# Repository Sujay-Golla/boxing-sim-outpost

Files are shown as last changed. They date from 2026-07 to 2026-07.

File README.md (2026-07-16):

# Boxing Simulator
By: Sujay Golla, Arush Sastry, Sreekar

## Inspiration
The inspiration for this project partially comes from VR experience, which uses body sensors to let users experience and interact with a different reality. Combined with our shared interests for combat sports, we chose to use robotic arms to simulate a boxing game and create a fun and interactive demo for Open Sauce.

## Challenges
The time constraint was the biggest challenge in designing, prototyping and refining our project. Since it was a hackathon, a lot of the wiring and 3D models were initial iterations and had to be adapted to create a working demo. Initially we were planning to make it a two-player interactive game but we had to scope it down to accomodate for the materials and timing constraints to a one-player score-based boxing game.

## Technical Features
The project involves a pair of 3-DOF robotic arms controlled by MPU-6050 IMU sensors in the form of an armband that users can wear to interact the board. Depending on the complexity and execution of a boxing move, players can score points and finish objectives. In a two-player extension, a boxing spar would take place, where the player with the most points would win. 

## CAD Model


## Wiring Diagram


## BOM

| Item Name | Qty | Price (USD) | Links |
|---|---:|---:|---|
| Orpheus Pi Pico | 1 | ~$5 | [Orpheus Pico](https://orpheuspico.hackclub.com/) |
| MG996 Servo | 12 | ~$40 | [Amazon](https://www.amazon.com/s?k=MG996R+servo) |
| MPU-6050 | 4 | ~$16 | [Adafruit](https://www.adafruit.com/product/3886) |
| LM25965 | 4 | ~$12 | [Amazon](https://www.amazon.com/s?k=LM2596+buck+converter) |
| M-F Jumper Wires | 30 | ~$3 | [Amazon](https://www.amazon.com/s?k=male+to+female+jumper+wires) |
| F-F Jumper Wires | 30 | ~$3 | [Amazon](https://www.amazon.com/s?k=female+to+female+jumper+wires) |
| M-M Jumper Wires | 30 | ~$3 | [Amazon](https://www.amazon.com/s?k=male+to+male+jumper+wires) |
| Bearings | 8 | ~$16 | [Amazon](https://www.amazon.com/s?k=608+bearings) |
| Pulley Belt | 2 m | ~$10 | [Amazon](https://www.amazon.com/s?k=timing+pulley+belt) |

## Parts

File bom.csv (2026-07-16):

Item Name | Qty | Price (USD) | Links
Orpheus Pi Pico | 1 | ~$5 | https://orpheuspico.hackclub.com/
MG996 Servo | 12 | ~$40 | https://www.amazon.com/s?k=MG996R+servo
MPU-6050 | 4 | ~$16 | https://www.adafruit.com/product/3886
LM25965 | 4 | ~$12 | https://www.amazon.com/s?k=LM2596+buck+converter
M-F Jumper Wires | 30 | ~$3 | https://www.amazon.com/s?k=male+to+female+jumper+wires
F-F Jumper Wires | 30 | ~$3 | https://www.amazon.com/s?k=female+to+female+jumper+wires
M-M Jumper Wires | 30 | ~$3 | https://www.amazon.com/s?k=male+to+male+jumper+wires
Bearings | 8 | ~$16 | https://www.amazon.com/s?k=608+bearings
Pulley Belt | 2 m | ~$10 | https://www.amazon.com/s?k=timing+pulley+belt

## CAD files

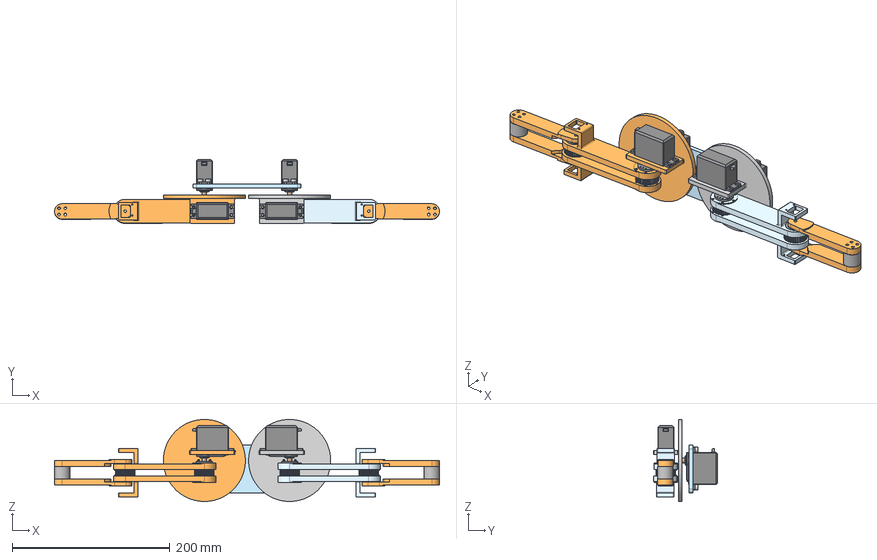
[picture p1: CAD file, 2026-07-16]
CAD/full-assembly.step
488.6 x 81.4 x 104.1 mm
Part 2-Mirrored
to print x 2
to print 2 x 2
to print-Mirrored x 2
to print 3 x 2
M4 Screw x 8
Servo MG996R_r1 x 3
Servo MG996R_r1-Mirrored
to print 4
to print 4-Mirrored

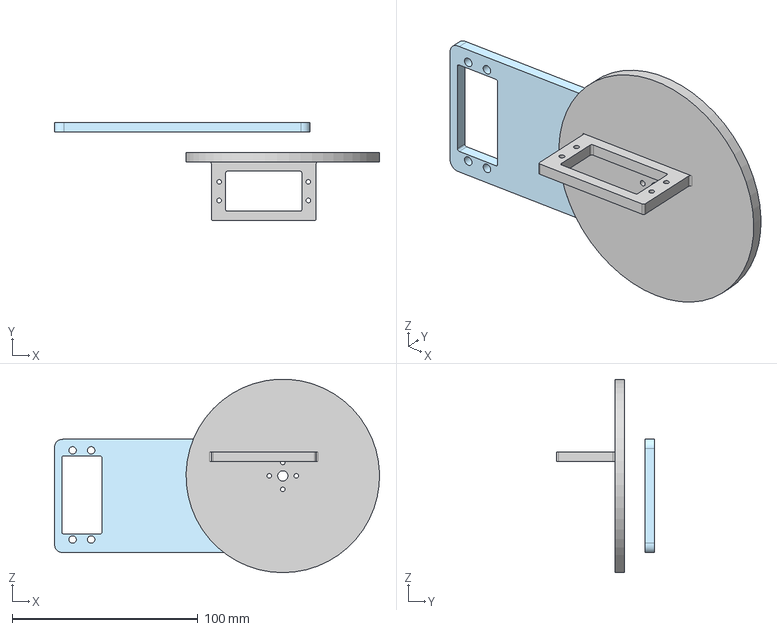
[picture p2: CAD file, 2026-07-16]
CAD/motor-mounts.step
175.0 x 52.7 x 104.1 mm

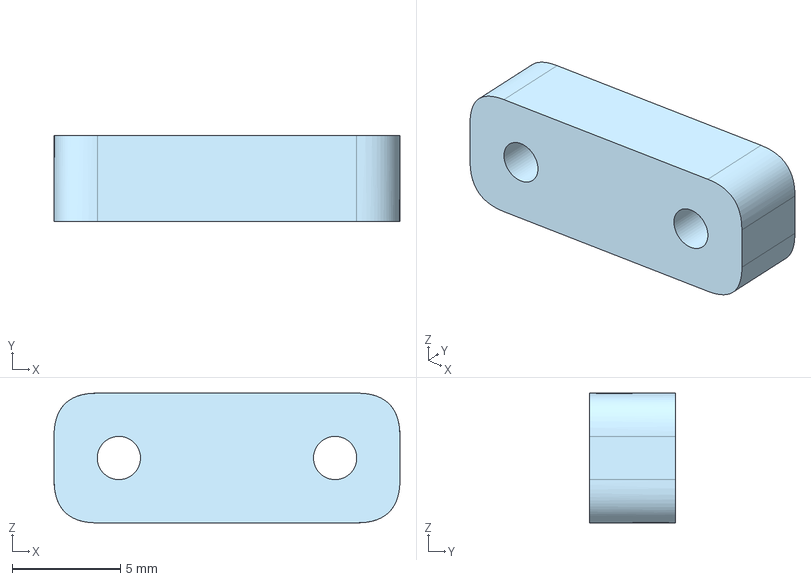
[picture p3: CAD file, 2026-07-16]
CAD/belt-closer.step
16.0 x 4.00 x 6.00 mm

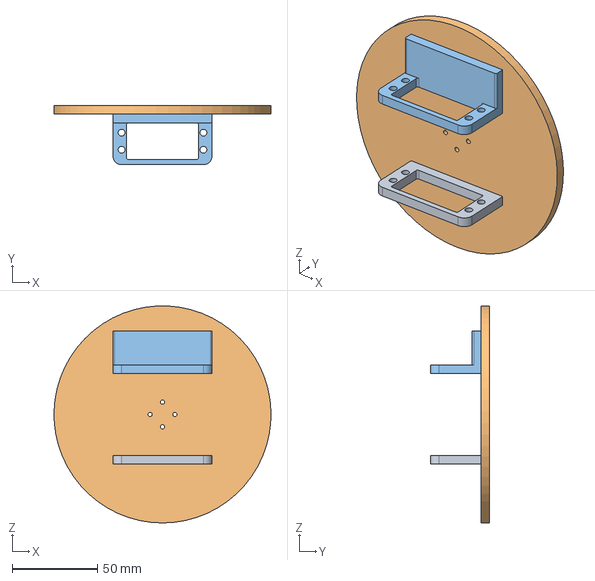
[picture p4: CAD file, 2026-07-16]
CAD/motor-mounts2.step
127.1 x 34.8 x 127.1 mm

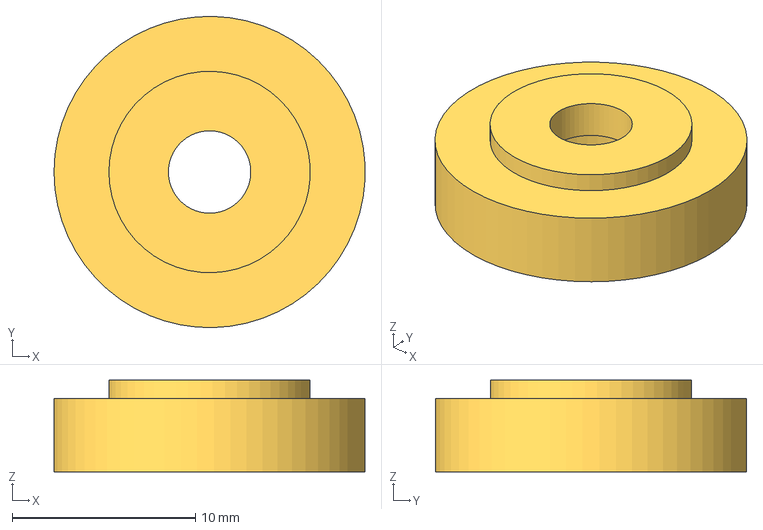
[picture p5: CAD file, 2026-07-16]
CAD/bearing-adaptor.step
17.0 x 17.0 x 5.00 mm

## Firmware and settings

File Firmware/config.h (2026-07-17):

/**
 * config.h — Global constants, pin map, data structures, and tuning parameters
 * for the 1-player dual-arm RP2040 avatar mirror system.
 *
 * MAJOR CHANGE (v2): Scoped down from 2-player boxing to 1-player Left/Right
 * arm avatar. Removed all match/scoring state. 6 servos (3 per arm).
 *
 * TFT_eSPI library setup:
 *   Copy TFT_eSPI_User_Setup.h into libraries/TFT_eSPI/User_Setup.h.
 */

#ifndef BOXING_CONFIG_H
#define BOXING_CONFIG_H

#include <Arduino.h>

// ---------------------------------------------------------------------------
// Arm / servo topology  [CHANGED: was NUM_PLAYERS=2, 6 servos each]
// ---------------------------------------------------------------------------
#define NUM_ARMS              2
#define SERVOS_PER_ARM        3
#define TOTAL_SERVOS          (NUM_ARMS * SERVOS_PER_ARM)   // 6 total

enum ArmId : uint8_t {
  ARM_LEFT  = 0,
  ARM_RIGHT = 1
};

/** Three DOF per arm: shoulder yaw, shoulder pitch, elbow pitch. */
enum ServoRole : uint8_t {
  SERVO_SHOULDER_YAW = 0,
  SERVO_SHOULDER_PITCH,
  SERVO_ELBOW_PITCH,
  SERVO_ROLE_COUNT
};

// ---------------------------------------------------------------------------
// I2C pin assignments  [CHANGED: Left=I2C0, Right=I2C1 — was Player1/Player2]
// ---------------------------------------------------------------------------
#define LEFT_I2C_SDA          4
#define LEFT_I2C_SCL          5
#define RIGHT_I2C_SDA         0
#define RIGHT_I2C_SCL         1

#define MPU6050_ADDR_LOW      0x68   // AD0 LOW  — upper arm
#define MPU6050_ADDR_HIGH     0x69   // AD0 HIGH — forearm

// ---------------------------------------------------------------------------
// Servo GPIO  [CHANGED: 6 servos on GP6–GP11, 3 per arm]
// ---------------------------------------------------------------------------
static const uint8_t SERVO_PINS[TOTAL_SERVOS] = {
  // Left arm
  13, 14, 15,   // Shoulder Yaw, Shoulder Pitch, Elbow Pitch
  // Right arm
  10, 11, 12  // Shoulder Yaw, Shoulder Pitch, Elbow Pitch
};

static const uint8_t SERVO_NEUTRAL[SERVO_ROLE_COUNT] = {
  90, 90, 90
};

struct ServoLimit {
  uint8_t minDeg;
  uint8_t maxDeg;
};

static const ServoLimit SERVO_LIMITS[SERVO_ROLE_COUNT] = {
  { 30, 150 },   // shoulder yaw
  { 45, 135 },   // shoulder pitch
  { 40, 140 }    // elbow pitch
};

static const float KINEMATIC_GAIN[SERVO_ROLE_COUNT] = {
  0.85f, 0.90f, 0.95f
};

// ---------------------------------------------------------------------------
// TFT SPI0 pins (unchanged)
// ---------------------------------------------------------------------------
#define TFT_PIN_SCK           18
#define TFT_PIN_MOSI          19
#define TFT_PIN_MISO          20
#define TFT_PIN_CS            21
#define TFT_PIN_DC            22
#define TFT_PIN_RST           26

// ---------------------------------------------------------------------------
// Timing (non-blocking cooperative scheduler)
// ---------------------------------------------------------------------------
#define SENSOR_INTERVAL_MS    10    // 100 Hz on Core 0
#define CONTROL_INTERVAL_MS   20    //  50 Hz on Core 1
#define DISPLAY_INTERVAL_MS   100   //  10 Hz on Core 1

// ---------------------------------------------------------------------------
// MPU-6050 / complementary filter tuning (unchanged)
// ---------------------------------------------------------------------------
#define MPU_GYRO_FS           0
#define MPU_ACCEL_FS          0
#define COMP_FILTER_ALPHA     0.96f
#define GYRO_LSB_PER_DPS_250  131.0f
#define ACCEL_LSB_PER_G_2     16384.0f

// ---------------------------------------------------------------------------
// Kinematics EMA smoothing
// ---------------------------------------------------------------------------
#define SERVO_EMA_BETA        0.25f

// ---------------------------------------------------------------------------
// Data structures  [CHANGED: explicit Left/Right IMU naming, no match state]
// ---------------------------------------------------------------------------

struct ImuAngles {
  float pitch;
  float roll;
  float yaw;
};

struct ImuState {
  ImuAngles angles;
  float     accelMagG;
  bool      healthy;
};

/** Snapshot published by Core 0 — explicit per-segment naming. */
struct SensorSnapshot {
  ImuState left_upper;
  ImuState left_forearm;
  ImuState right_upper;
  ImuState right_forearm;
  uint32_t timestampUs;
  uint32_t sequence;
};

/** Smoothed servo commands for one arm (degrees). */
struct ArmServoCommands {
  float shoulder_yaw;
  float shoulder_pitch;
  float elbow_pitch;
};

/** Runtime performance counters for diagnostic display (Core 1). */
struct SystemStats {
  float sensorFps;    // Core 0 publish rate (estimated on Core 1)
  float controlFps;   // kinematics loop rate
  float displayFps;   // TFT refresh rate
};
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

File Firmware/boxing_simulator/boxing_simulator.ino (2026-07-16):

/**
 * boxing_simulator.ino — 1-player dual-arm avatar mirror (RP2040 Pico).
 *
 * MAJOR CHANGE (v2): Single operator, Left + Right arms. No match logic.
 *
 * Dual-core layout (Earle Philhower RP2040 core):
 *   Core 0 — setup() / loop()     : MPU-6050 acquisition @ 100 Hz
 *   Core 1 — setup1() / loop1()   : kinematics, servos, diagnostic TFT
 *
 * Serial @ 115200: 'S' = print sensor angles
 */

#include "config.h"
#include "sensors.h"
#include "kinematics.h"
#include "display.h"

static uint32_t g_lastControlMs = 0;
static SystemStats g_stats = {};

// Control-loop FPS measurement
static uint32_t g_ctrlFpsWindowStart = 0;
static uint16_t g_ctrlFrameCount = 0;

static SensorSnapshot readSensorMailbox() {
  const uint8_t idx = g_sensorMailbox.readIndex;
  return g_sensorMailbox.buffers[idx];
}

// =============================================================================
// CORE 0 — Sensor acquisition
// =============================================================================

void setup() {
  Serial.begin(115200);
  while (!Serial && (millis() < 3000)) { }

  Serial.println(F("Avatar Mirror — Core 0 starting sensors"));

  if (!g_sensors.begin()) {
    Serial.println(F("WARNING: One or more IMUs failed init."));
  } else {
    Serial.println(F("All 4 IMUs initialized (L/R upper+forearm)."));
  }
}

void loop() {
  g_sensors.update(millis());
  yield();
}

// =============================================================================
// CORE 1 — Kinematics, servos, diagnostic display
// =============================================================================

void setup1() {
  {
    const uint32_t t0 = millis();
    while ((millis() - t0) < 200) { yield(); }
  }

  Serial.println(F("Core 1 starting kinematics + display"));
  g_kinematics.begin();
  g_display.begin();
  g_lastControlMs    = millis();
  g_ctrlFpsWindowStart = millis();
  Serial.println(F("Ready — mirror mode active. Send 'S' for serial debug."));
}

void loop1() {
  const uint32_t nowMs = millis();

  if (Serial.available()) {
    const char c = Serial.read();
    if ((c == 'S' || c == 's') && g_sensors.isReady()) {
      const SensorSnapshot s = readSensorMailbox();
      Serial.print(F("L_up P=")); Serial.print(s.left_upper.angles.pitch, 1);
      Serial.print(F(" L_fr P=")); Serial.print(s.left_forearm.angles.pitch, 1);
      Serial.print(F(" R_up P=")); Serial.print(s.right_upper.angles.pitch, 1);
      Serial.print(F(" R_fr P=")); Serial.println(s.right_forearm.angles.pitch, 1);
    }
  }

  if (!g_sensors.isReady()) {
    yield();
    return;
  }

  const SensorSnapshot snap = readSensorMailbox();

  if ((nowMs - g_lastControlMs) >= CONTROL_INTERVAL_MS) {
    g_lastControlMs = nowMs;
    g_kinematics.update(snap, nowMs);

    g_ctrlFrameCount++;
    if ((nowMs - g_ctrlFpsWindowStart) >= 1000) {
      g_stats.controlFps = g_ctrlFrameCount /
                           ((nowMs - g_ctrlFpsWindowStart) * 0.001f);
      g_ctrlFrameCount     = 0;
      g_ctrlFpsWindowStart = nowMs;
    }
  }

  g_display.update(snap,
                   g_kinematics.commands(ARM_LEFT),
                   g_kinematics.commands(ARM_RIGHT),
                   g_stats,
                   nowMs);

  yield();
}

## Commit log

2026-07-16 Adding CAD
    [bearing-adaptor.step, belt-closer.step, full-assembly.step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]
2026-07-16 Adding Wiring Diagram
    [boxing_sim.kicad_sch]
2026-07-16 Update README with CAD model and wiring diagram images
    Added images for CAD model and wiring diagram in README.
2026-07-16 Adding bom.csv
    [bom.csv]
